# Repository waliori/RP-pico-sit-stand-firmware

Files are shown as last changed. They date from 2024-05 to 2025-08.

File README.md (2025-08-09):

# Smart Sit-Stand Desk Controller






A comprehensive and intelligent sit-stand desk controller built on Raspberry Pi Pico W, featuring WiFi connectivity, web API, and sophisticated safety mechanisms. Advanced collision detection with PCA is currently under development.

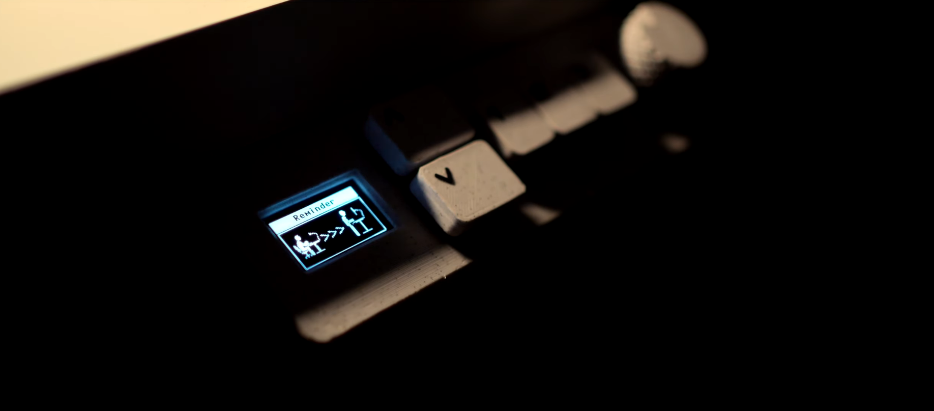
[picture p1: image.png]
The controller! Controller


🎬 **[Watch the Build Journey](https://www.youtube.com/watch?v=PKzvHBzcGJ4)** - Experience the development adventure and see the system in action

## 🌟 Features

### 🔧 Hardware Integration
- **Raspberry Pi Pico W** - Main controller with WiFi connectivity
- **H-Bridge Motor Control** - Precise linear actuator control with PWM
- **Multi-Sensor Safety System**:
  - Current sensing (ACS712 30A sensor)
  - 3-axis accelerometer (ADXL345)
  - Dual quadrature encoders (separate position tracking and UI navigation)
- **Professional UI**:
  - 128x64 OLED display (SH1106)
  - Dual rotary encoder system (UI navigation + position feedback)
  - Multiple tactile buttons
  - Audio/haptic feedback (buzzer + vibration motor)

### 🧠 Intelligent Features
- **Advanced Collision Detection** using Principal Component Analysis (PCA) ⚠️ *Work In Progress*
- **Multi-sensor Fusion** for enhanced safety and precision ⚠️ *Collision detection WIP*
- **Basic Safety Monitoring** with current sensing and position limits
- **WiFi Connectivity** with web-based configuration interface
- **RESTful API** for remote control and integration
- **Preset Height Management** (3 programmable positions)
- **Smart Sleep/Wake System** with posture reminders
- **Comprehensive Calibration System** for setup and maintenance
- **Dual Encoder System** - Separate position feedback and UI navigation

### 🔒 Safety & Reliability
- **Current Monitoring** to prevent motor overload
- **Position Limits** with software and hardware enforcement  
- **Graceful Error Handling** with user feedback
- **Persistent Configuration** storage with JSON files
- **Thread-safe Operations** with proper locking mechanisms
- **Future: Advanced Collision Detection** ⚠️ *Under Development*

## 📋 Table of Contents

1. [Project Status](#-project-status)
2. [Hardware Requirements](#-hardware-requirements)
3. [Pin Configuration](#-pin-configuration)
4. [Software Architecture](#-software-architecture)
5. [Installation & Setup](#-installation--setup)
6. [Configuration](#-configuration)
7. [API Reference](#-api-reference)
8. [Troubleshooting](#-troubleshooting)
9. [Contributing](#-contributing)
10. [License](#-license)

## 📊 Project Status

This project is part of the **[Micropython sit/stand smart table](https://github.com/users/waliori/projects/1)** development roadmap.

### ✅ Completed Features
- Core motor control with H-bridge integration
- WiFi connectivity and web interface
- OLED display with menu system
- Position tracking with encoders
- Preset height management
- RESTful API for remote control
- Configuration system with JSON storage

### 🚧 Work In Progress
- **Advanced Collision Detection** (PCA-based algorithm)
- **Multi-sensor Fusion** for enhanced safety
- **API collision detection endpoints**
- **Enhanced user guide and documentation**
- **Audio/sound system improvements**

### 📅 Planned Features
- Over-the-air (OTA) updates
- Enhanced web interface
- Mobile app integration
- Advanced logging and diagnostics
- Community-contributed features

### 🔗 Project Links
- **Main Project Board**: https://github.com/users/waliori/projects/1
- **Repository**: https://github.com/waliori/RP-pico-sit-stand-firmware
- **Issues & Features**: https://github.com/waliori/RP-pico-sit-stand-firmware/issues

## 🔌 Hardware Requirements

### Core Components

| Component | Model/Specification | Quantity | Notes |
|---|---|---|---|
| **Microcontroller** | Raspberry Pi Pico W | 1 | WiFi-enabled version required |
| **Motor Driver** | H-Bridge (capable of handling desk motor) | 1 | PWM-controlled, sufficient current rating |
| **Current Sensor** | ACS712-30A | 1 | 30A version, 66mV/A sensitivity |
| **Accelerometer** | ADXL345 | 1 | 3-axis, I2C interface |
| **Display** | SH1106 OLED 128x64 | 1 | I2C interface |
| **Position Encoder** | Quadrature Encoder (left side) | 1 | Motor position feedback only |
| **UI Encoder** | Rotary Encoder with Button (right side) | 1 | UI navigation only |
| **Buttons** | Tactile Push Buttons | 5 | Up, Down, Preset 1-3 |
| **Audio Feedback** | PWM Buzzer | 1 | Piezo buzzer, PWM-driven |
| **Haptic Feedback** | Vibration Motor | 1 | Small DC motor |

### Supporting Components

- **12V Power Supply**: For motor power
- **3.3V Regulator**: Powers all electronics from 12V  
- **Custom PCB**: For component mounting and connections
- **Connection Wires**: For linking components
- **3D Printed Parts**: Custom enclosures and mounting solutions

**Notes**: 
- All electronics run on 3.3V (except motor which uses 12V)
- Uses Pico W's internal pull-up resistors - no external resistors needed
- **🎨 3D Models**: Full CAD files available at [OnShape CAD Document](https://cad.onshape.com/documents/f9483c31494feda60f507100/w/67832ca84d886d2bfa4006b1/e/62aed646cd76d0a16e7ccfc5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)
- **📐 Wiring Diagrams**: 
  - [Wiring Diagram (PDF)](docs/schematics/wiring-diagram.pdf) - Complete breadboard-style wiring schematic
  - [Wiring Diagram (Fritzing)](docs/schematics/wiring-diagram.fzz) - Editable Fritzing source file
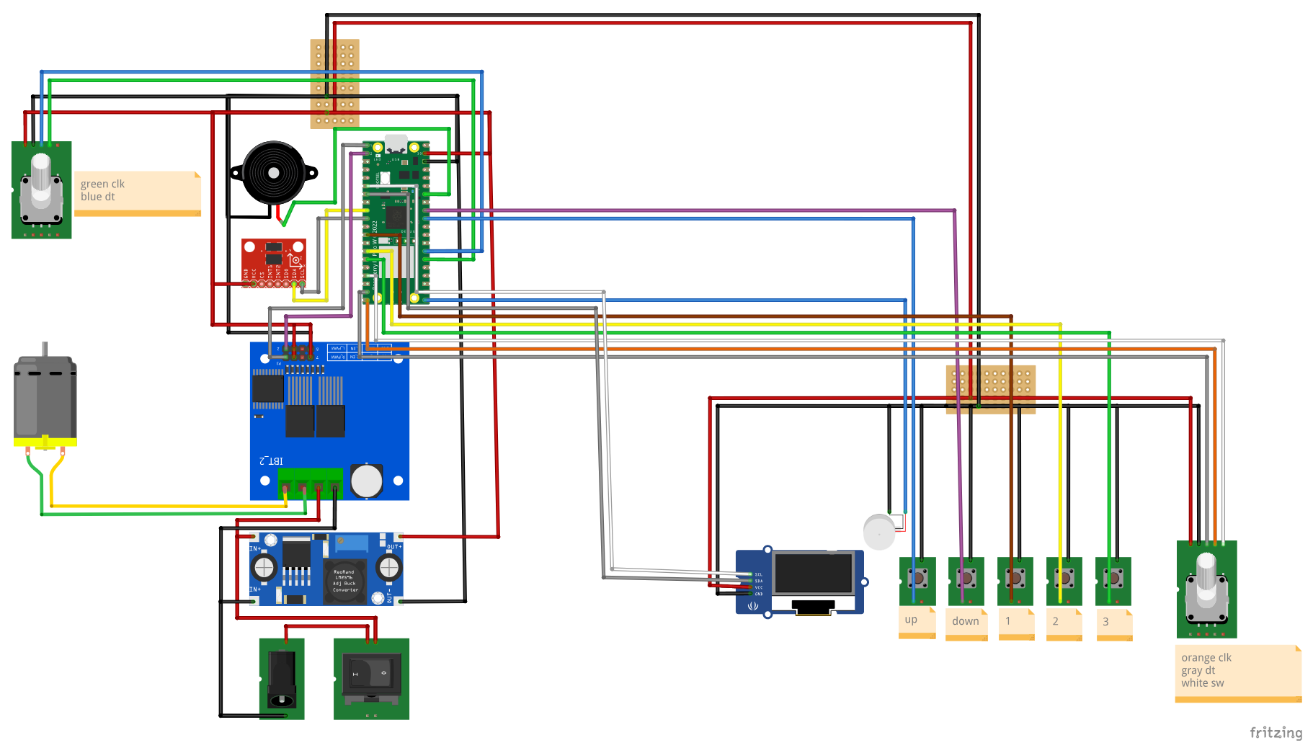
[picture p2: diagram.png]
The diagram! Wiring diagram
  

## 📍 Pin Configuration

### Raspberry Pi Pico W Pinout

```
╭─────────────────────────────────────╮
│              GPIO ASSIGNMENTS        │
├─────────────────────────────────────┤
│ Motor Control:                      │
│   GPIO 0  - H-Bridge R_PWM (Right)  │
│   GPIO 1  - H-Bridge L_PWM (Left)   │
│                                     │
│ Display & Communication (I2C0):     │
│   GPIO 4  - OLED SDA                │
│   GPIO 5  - OLED SCL                │
│                                     │
│ Sensors (I2C1):                     │
│   GPIO 6  - Accelerometer SDA       │
│   GPIO 7  - Accelerometer SCL       │
│                                     │
│ User Interface:                     │
│   GPIO 9  - Preset Button 1         │
│   GPIO 10 - Preset Button 2         │
│   GPIO 11 - Preset Button 3         │
│   GPIO 13 - UI Encoder Button       │
│   GPIO 14 - UI Encoder DT           │
│   GPIO 15 - UI Encoder CLK          │
│                                     │
│ Motor Position Encoder (Left):      │
│   GPIO 20 - Position Encoder CLK    │
│   GPIO 21 - Position Encoder DT     │
│                                     │
│ Audio/Haptic Feedback:              │
│   GPIO 16 - Vibration Motor         │
│   GPIO 22 - PWM Buzzer              │
│                                     │
│ Control Buttons:                    │
│   GPIO 26 - Down Button             │
│   GPIO 27 - Up Button               │
│                                     │
│ Analog Input:                       │
│   GPIO 28 - Current Sensor (ADC)    │
╰─────────────────────────────────────╯
```

### Connection Diagrams

#### Power Connections
```
Pico W 3.3V ──┬── All Electronics:
                ├── OLED Display
                ├── Accelerometer
                ├── Current Sensor
                ├── Rotary Encoders
                └── Buttons & Buzzer

12V Supply ─────── Motor (via H-Bridge)

Common GND ─────── All components
```

#### I2C Bus Configuration
```
I2C0 (Display):          I2C1 (Sensors):
GPIO 4 (SDA) ──── OLED   GPIO 6 (SDA) ──── ADXL345
GPIO 5 (SCL) ──── OLED   GPIO 7 (SCL) ──── ADXL345
```

#### Dual Encoder Configuration
```
Left Encoder (Position):     Right Encoder (UI):
GPIO 20 (CLK) ──── Motor     GPIO 15 (CLK) ──── Menu Navigation
GPIO 21 (DT)  ──── Position  GPIO 14 (DT)  ──── Menu Navigation
                             GPIO 13 (SW)  ──── Menu Button
```

## 🏗️ Software Architecture

### System Overview

```
┌─────────────────────────────────────────────────────────────┐
│                     Application Layer                       │
├─────────────────────────────────────────────────────────────┤
│  main.py           │  Setup & Main Loop                     │
│  menu.py           │  User Interface Management             │
│  wifi.py           │  Network & Web Interface              │
├─────────────────────────────────────────────────────────────┤
│                    Control Layer                            │
├─────────────────────────────────────────────────────────────┤
│  motor.py          │  Motor Control & Basic Safety         │
│  calibration.py    │  System Calibration & Configuration   │
│  presets.py        │  Height Preset Management             │
│  collision.py      │  🚧 Collision Detection (WIP)         │
├─────────────────────────────────────────────────────────────┤
│                   Hardware Layer                            │
├─────────────────────────────────────────────────────────────┤
│  display.py        │  OLED Display Management               │
│  accelerometer.py  │  Motion Sensor Interface              │
│  acs712.py         │  Current Sensor Interface             │
│  buzz_vib.py       │  Audio/Haptic Feedback                │
├─────────────────────────────────────────────────────────────┤
│                   Support Layer                             │
├─────────────────────────────────────────────────────────────┤
│  songs.py          │  Audio Notification Patterns          │
│  rtttl.py          │  Music Format Parser                  │
│  sh1106.py         │  OLED Display Driver                  │
│  writer.py         │  Font Rendering System                │
└─────────────────────────────────────────────────────────────┘
```

### Core Modules

#### 1. Motor Control System (`motor.py`)
- **PWM Motor Control**: Precision speed and direction control
- **Encoder Integration**: Real-time position feedback
- **Basic Safety Monitoring**: Current monitoring and position limits
- **API Support**: Asynchronous motor control for web interface
- **Future: PCA-based Analysis** ⚠️ *Under Development*

#### 2. Collision Detection (`collision.py`) 🚧 *Work In Progress*
- **⚠️ Development Status**: Advanced collision detection is currently being implemented
- **Planned Features**: Principal Component Analysis for statistical anomaly detection
- **Future Capabilities**: Multi-sensor fusion (accelerometer + current + RPM)
- **Target Features**: Adaptive thresholds and direction-specific detection
- **Current Status**: Basic framework in place, algorithm implementation ongoing

#### 3. Calibration System (`calibration.py`)
- **Multi-phase Setup**: Height limits, sensor baselines, safety thresholds
- **Persistent Storage**: JSON-based configuration management
- **Real-time Updates**: Dynamic recalibration capabilities
- **Height Mapping**: Encoder-to-real-world height conversion
- **Safety Validation**: Limit verification and enforcement

#### 4. WiFi & Web Interface (`wifi.py`)
- **Auto-connection**: Intelligent network discovery and connection
- **Access Point Mode**: Fallback configuration interface
- **Web Portal**: HTML-based setup and control interface
- **RESTful API**: Complete remote control capabilities
- **Security**: Password-protected networks and saved credentials

#### 5. Display System (`display.py`)
- **Multi-font Support**: 20pt and 30pt font rendering
- **Icon System**: WiFi, lock, sound, and status indicators
- **Menu Framework**: Hierarchical navigation system
- **Animation Support**: Progress bars and visual feedback
- **Power Management**: Sleep and wake functionality

### Data Flow Architecture

```
┌─────────────────────────────────────────────────────────────┐
│                    DUAL ENCODER SYSTEM                     │
├─────────────────────────────────────────────────────────────┤
│  Position Encoder (Left) ──► Motor Control ──► Basic Safety │
│     GPIO 20/21                     │              │         │
│                                    ▼              ▼         │
│  UI Encoder (Right) ──► Display ──► Height Display Safety   │
│     GPIO 13/14/15       System       Updates     Actions   │
│                           │                                 │
│  Physical Buttons ────────┤                                 │
│  (Up/Down/Presets)        │                                 │
│                           ▼                                 │
│                      Menu Navigation                        │
└─────────────────────────────────────────────────────────────┘
                           │
                           ▼
┌─────────────────────────────────────────────────────────────┐
│                    SENSOR FUSION                           │
├─────────────────────────────────────────────────────────────┤
│  Accelerometer (GPIO 6/7) ──┐                              │
│                              ├─► Safety Monitoring         │
│  Current Sensor (GPIO 28) ───┘         │                   │
│                                         ▼                   │
│                              🚧 Future: Advanced Collision  │
│                                 Detection (PCA-based)       │
└─────────────────────────────────────────────────────────────┘
                           │
                           ▼
┌─────────────────────────────────────────────────────────────┐
│                  CONTROL INTERFACES                        │
├─────────────────────────────────────────────────────────────┤
│  Web API (WiFi) ──────────┐                                │
│                           ├─► Motor Commands               │
│  Physical Controls ───────┘     │                          │
│  (Buttons/Encoders)              ▼                          │
│                            H-Bridge Control                │
│                            (GPIO 0/1 PWM)                  │
└─────────────────────────────────────────────────────────────┘
                           │
                           ▼
┌─────────────────────────────────────────────────────────────┐
│                 PERSISTENT STORAGE                         │
├─────────────────────────────────────────────────────────────┤
│  settings.json ◄─── Calibration System                     │
│  presets.json  ◄─── Preset Management                      │
│  state.json    ◄─── Current Position                       │
│  saved_wifi.json ◄─ Network Credentials                    │
└─────────────────────────────────────────────────────────────┘
```

## 🚀 Installation & Setup

### Prerequisites

1. **MicroPython Firmware**: Install latest MicroPython on Raspberry Pi Pico W
2. **Development Environment**: 
   - Thonny IDE (recommended for beginners)
   - VS Code with MicroPython extension
   - Command line tools (ampy, rshell, mpremote)

### Step 1: Hardware Assembly

1. **Connect Components** according to the pin configuration above
2. **Verify Power Supply** ratings and connections
3. **Test Individual Components** before full assembly
4. **Secure Connections** and check for shorts

### Step 2: Firmware Installation

```bash
# Clone the repository
git clone https://github.com/waliori/RP-pico-sit-stand-firmware.git
cd RP-pico-sit-stand-firmware

# Upload files to Pico W (using mpremote)
mpremote fs cp *.py :
mpremote fs cp lib/* :lib/

# Alternative: Using Thonny IDE
# 1. Open Thonny
# 2. Configure for Raspberry Pi Pico
# 3. Upload all .py files to the device
```

### Step 3: Initial Configuration

1. **Power On**: The system will start in calibration mode
2. **Height Calibration**:
   - Move desk to highest position → Press and hold rotary encoder
   - Set maximum height value using rotary encoder
   - Move desk to lowest position → Press and hold rotary encoder  
   - Set minimum height value using rotary encoder
3. **WiFi Setup**: 
   - Connect to "PicoW" access point (password: waliori123)
   - Navigate to 192.168.4.1
   - Configure WiFi credentials

### Step 4: Safety Calibration

1. **Collision Calibration**:
   - Access "Collision Reset" from main menu
   - Move desk through full range while system learns normal operation
   - Confirm calibration completion

2. **Verification**:
   - Test all movement directions
   - Verify collision detection with safe obstacles
   - Confirm preset functionality

## ⚙️ Configuration

### System Settings (`settings.json`)

```json
{
  "min_encoder": 0,
  "max_encoder": 5000,
  "min_real": 72.0,
  "max_real": 120.0,
  "sleep_time": 30,
  "reminder_time": 5400,
  "rpm_up": 120.0,
  "rpm_down": 115.0,
  "current_up": 2.5,
  "current_down": 2.2,
  "accel_up": [100, 150, 980],
  "accel_down": [95, 145, 985],
  "principal_components_up": [[...], [...]],
  "principal_components_down": [[...], [...]],
  "projected_mean_up": [0.5, 0.3],
  "projected_mean_down": [0.4, 0.2]
}
```

### WiFi Configuration (`saved_wifi.json`)

```json
{
  "HomeNetwork": "password123",
  "OfficeWiFi": "securepass456"
}
```

### Preset Heights (`presets.json`)

```json
{
  "1": 2500,
  "2": 3750,
  "3": 4200
}
```

### Menu System Navigation

```
Main Menu
├── WiFi
│   ├── Connect to saved networks
│   ├── Scan for new networks
│   ├── Access Point mode
│   └── API toggle
├── Configuration
│   ├── Sleep timer settings
│   ├── Min/Max height adjustment
│   ├── Posture reminder timer
│   ├── Vibration on/off
│   └── Sound settings
├── Lock/Unlock
├── Show Presets
├── Show Min/Max
├── Collision Reset
└── Factory Reset
```

## 🌐 API Reference

### Base URL
```
http://<pico-ip-address>/
```

### Endpoints

#### Status & Information

**Get Current Height**
```http
GET /get_height
```
Response:
```json
{"height": "95.5"}
```

**Get Min/Max Heights**
```http
GET /get_minmax
```
Response:
```json
{"min": 72.0, "max": 120.0}
```

**Get Presets**
```http
GET /get_presets
```
Response:
```json
["1: 95.5", "2: 110.0", "3: 115.2"]
```

**Check Lock Status**
```http
GET /islocked
```
Response:
```json
{"locked": false}
```

#### Control Commands

**Move Up**
```http
GET /forward
```

**Move Down**
```http
GET /backward
```

**Stop Movement**
```http
GET /stop
```

**Go to Specific Height**
```http
GET /go?height=100.5
```

**Go to Preset**
```http
GET /go_preset?preset=1
```

#### Security & Settings

**Lock Desk**
```http
GET /lock
```

**Unlock Desk**
```http
GET /unlock
```

**Set Minimum Height**
```http
GET /set_min?min=70.0
```

**Set Maximum Height**
```http
GET /set_max?max=125.0
```

### Response Format

All API responses include CORS headers and follow this structure:

**Success Response:**
```json
{
  "status": "ok",
  "data": "..."
}
```

**Error Response:**
```json
{
  "status": "nok",
  "error": "Description of error"
}
```

## 🔧 Advanced Features

### Current Safety Features

- **Position Limits**: Software-enforced minimum and maximum heights
- **Current Monitoring**: Motor current sensing for overload protection
- **Manual Controls**: Physical buttons for direct desk control
- **Emergency Stop**: Immediate motor shutdown capability

### 🚧 Future: Advanced Collision Detection (Work In Progress)

The system is being developed to include Principal Component Analysis (PCA) for sophisticated obstacle detection:

**Planned Implementation**:
1. **Multi-sensor Data Collection**: 3-axis accelerometer, motor current, RPM
2. **Statistical Analysis**: Real-time normalization and PCA projection
3. **Adaptive Thresholds**: Dynamic sensitivity adjustment
4. **Direction-specific Calibration**: Separate learning for up/down movement

**Development Status**: Framework implemented, algorithm integration in progress

### Power Management

- **Sleep Mode**: OLED turns off after configurable timeout
- **Wake on Input**: Any button press or encoder movement
- **Posture Reminders**: Configurable alerts for movement
- **Low Power WiFi**: Optimized power management for wireless

### Security Features

- **Physical Lock**: Disable all movement commands
- **API Authentication**: Future expansion capability
- **Safe Mode**: Reduced sensitivity for maintenance
- **Position Limits**: Software-enforced boundaries

## 🐛 Troubleshooting

### Common Issues

**Problem**: Desk doesn't move when buttons are pressed
- **Check**: Motor driver connections and power supply
- **Check**: H-bridge enable signals and PWM outputs  
- **Check**: Encoder connections for position feedback
- **Solution**: Verify all connections match pin configuration

**Problem**: Basic safety monitoring issues
- **Check**: Current sensor calibration and connections
- **Check**: Position encoder feedback
- **Solution**: Verify sensor connections and recalibrate system
- **Note**: Advanced collision detection is under development

**Problem**: WiFi connection fails
- **Check**: Network credentials in saved_wifi.json
- **Check**: WiFi signal strength and network availability
- **Solution**: Use access point mode for reconfiguration

**Problem**: Display shows incorrect height
- **Check**: Encoder connections and mechanical coupling
- **Solution**: Run full height calibration sequence

**Problem**: System freezes or becomes unresponsive
- **Check**: Power supply stability and current capacity
- **Check**: I2C bus conflicts or wiring issues
- **Solution**: Power cycle and check console output

### Debug Mode

Enable debug output by modifying `main.py`:

```python
DEBUG = True  # Add this line at the top

# Add debug prints throughout code
if DEBUG:
    print(f"Debug: Current height = {height}")
```

### Log Analysis

Monitor system behavior through UART:

```bash
# Using screen (Linux/Mac)
screen /dev/ttyACM0 115200

# Using PuTTY (Windows)
# Connect to COM port at 115200 baud
```

### Factory Reset

1. **Software Reset**: Access "Factory Reset" from main menu
2. **Hardware Reset**: Hold BOOTSEL button while powering on
3. **Full Reinstall**: Re-upload all firmware files

## 🤝 Contributing

We welcome contributions to improve this project!

### Development Setup

1. **Fork the Repository**
2. **Create Feature Branch**: `git checkout -b feature/amazing-feature`
3. **Install Development Tools**:
   ```bash
   pip install micropython-stubs
   pip install black  # Code formatting
   pip install pylint # Code analysis
   ```

### Code Standards

- **Python Style**: Follow PEP 8 guidelines
- **Documentation**: Include docstrings for all functions
- **Comments**: Explain complex logic and hardware interactions
- **Testing**: Test on actual hardware before submitting

### Contribution Areas

- **Hardware Support**: Additional sensor integrations
- **Safety Features**: Enhanced collision detection algorithms
- **UI Improvements**: Better display layouts and animations
- **API Extensions**: Additional control endpoints
- **Documentation**: Tutorials, guides, and examples

### Pull Request Process

1. **Update Documentation** for any new features
2. **Test Thoroughly** on hardware
3. **Update Version Numbers** if applicable
4. **Submit Pull Request** with clear description

## 📜 License

This project is licensed under the MIT License - see the [LICENSE](LICENSE) file for details.

```
MIT License

Copyright (c) 2024 waliori

Permission is hereby granted, free of charge, to any person obtaining a copy
of this software and associated documentation files (the "Software"), to deal
in the Software without restriction, including without limitation the rights
to use, copy, modify, merge, publish, distribute, sublicense, and/or sell
copies of the Software, and to permit persons to whom the Software is
furnished to do so, subject to the following conditions:

The above copyright notice and this permission notice shall be included in all
copies or substantial portions of the Software.

THE SOFTWARE IS PROVIDED "AS IS", WITHOUT WARRANTY OF ANY KIND, EXPRESS OR
IMPLIED, INCLUDING BUT NOT LIMITED TO THE WARRANTIES OF MERCHANTABILITY,
FITNESS FOR A PARTICULAR PURPOSE AND NONINFRINGEMENT. IN NO EVENT SHALL THE
AUTHORS OR COPYRIGHT HOLDERS BE LIABLE FOR ANY CLAIM, DAMAGES OR OTHER
LIABILITY, WHETHER IN AN ACTION OF CONTRACT, TORT OR OTHERWISE, ARISING FROM,
OUT OF OR IN CONNECTION WITH THE SOFTWARE OR THE USE OR OTHER DEALINGS IN THE
SOFTWARE.
```

## 🙏 Acknowledgments

- **Raspberry Pi Foundation** for the excellent Pico W platform
- **MicroPython Community** for the robust embedded Python implementation
- **Open Source Libraries**: SH1106, ADXL345, and other hardware drivers
- **Contributors**: All developers who have helped improve this project

## 📞 Support

- **Issues**: [GitHub Issues](https://github.com/waliori/RP-pico-sit-stand-firmware/issues)
- **Discussions**: [GitHub Discussions](https://github.com/waliori/RP-pico-sit-stand-firmware/discussions)
- **Build Video**: [🎬 YouTube Documentary](https://www.youtube.com/watch?v=PKzvHBzcGJ4) - Complete build process
- **Email**: Contact the maintainer through GitHub profile

---

**⚠️ Safety Notice**: This controller manages potentially dangerous mechanical equipment. Always verify all safety features are working correctly before use. Never bypass safety mechanisms. Use appropriate electrical protection and follow local electrical codes.

**🔌 Electrical Warning**: This project involves mains-powered equipment. Ensure proper electrical isolation and safety measures. When in doubt, consult a qualified electrician.

---

Made with ❤️ by [waliori](https://walior.it) | [Project Website](https://github.com/waliori/RP-pico-sit-stand-firmware)

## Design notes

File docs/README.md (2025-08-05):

# Smart Sit-Stand Desk Controller - Documentation

Documentation for the Smart Sit-Stand Desk Controller project built with Raspberry Pi Pico W and MicroPython.

🎬 **[Watch the Build Journey](https://www.youtube.com/watch?v=PKzvHBzcGJ4)** - Experience the development adventure and see the finished system in action.

⚠️ **Project Status**: Advanced collision detection features are currently Work In Progress as part of the [Micropython sit/stand smart table project](https://github.com/users/waliori/projects/1).

## 📋 Documentation

### Hardware
- **[Hardware Overview](hardware/overview.md)** - Components and pin assignments
- **[Bill of Materials](hardware/bom.md)** - Electronic components list
- **[3D Models & CAD Files](https://cad.onshape.com/documents/f9483c31494feda60f507100/w/67832ca84d886d2bfa4006b1/e/62aed646cd76d0a16e7ccfc5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)** - Open-source CAD models

### Software  
- **[System Architecture](software/architecture.md)** - Software design and modules

### API
- **[REST API Reference](api/rest-api.md)** - HTTP API documentation

### Setup
- **[Quick Start Guide](setup/quick-start.md)** - Setup instructions

## 🎯 Quick Navigation

### For New Users
1. Check [Hardware Overview](hardware/overview.md) for components
2. Follow [Quick Start Guide](setup/quick-start.md) for setup
3. Use [REST API Reference](api/rest-api.md) for control

### For Developers
1. Review [System Architecture](software/architecture.md)
2. Study [REST API Reference](api/rest-api.md)

## 📋 Project Overview

This documentation covers a sit-stand desk controller featuring:

- **Basic Safety**: Position limits, current monitoring
- **WiFi Control**: Web interface and REST API  
- **OLED Display**: Menu navigation with rotary encoder
- **Position Tracking**: Encoder feedback
- **Future: Advanced Collision Detection** ⚠️ PCA-based (under development)

### 🎬 Build Story

Experience the complete development journey in the [YouTube documentary](https://www.youtube.com/watch?v=PKzvHBzcGJ4).

## 📈 Project Status

### ✅ Completed Features
- Motor control and position tracking
- WiFi connectivity and web interface
- Basic safety monitoring (current sensing, position limits)
- OLED display with menu navigation
- RESTful API for remote control

### 🚧 Work In Progress
- **Advanced Collision Detection**: PCA-based algorithm implementation

### 🔗 Project Links
- **🎬 Build Documentary**: https://www.youtube.com/watch?v=PKzvHBzcGJ4
- **Main Project Board**: https://github.com/users/waliori/projects/1
- **Repository**: https://github.com/waliori/RP-pico-sit-stand-firmware

---

**📞 Support**: [GitHub Issues](https://github.com/waliori/RP-pico-sit-stand-firmware/issues)

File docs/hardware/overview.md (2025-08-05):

# Hardware Overview

Hardware components and connections for the Smart Sit-Stand Desk Controller.

## 🔌 Core Components

### Primary Controller
- **Raspberry Pi Pico W** - Main microcontroller with WiFi

### Motor Control System
- **BTS7960B H-Bridge** - Motor driver module
- **37GB555 Geared Motor** - 12V 180RPM DC motor with encoder

### Sensor System
- **ACS712-30A** - Current sensor module
- **ADXL345** - 3-axis accelerometer

### User Interface
- **SH1106 OLED** - 128x64 monochrome display
- **KY-040 Rotary Encoder** - 360° rotary encoder with button (1x UI navigation)
- **KY-040 Rotary Encoder** - 360° rotary encoder (1x motor position feedback)
- **Tactile Buttons** - Push buttons for controls (5x)

### Additional Components
- **12V Power Adapter** - AC to DC power supply
- **LM2596 Buck Converter** - DC-DC step down module
- **Buzzer** - Piezo buzzer (PWM driven)
- **Vibration Motor** - Coin vibration motor 3V
- **Connection Wires** - For linking components
- **3D Printed Enclosures** - Custom housings and mounts (CAD files available)

## 🔗 Pin Assignments

| GPIO | Function | Component | Notes |
|---|---|---|---|
| 0 | PWM | H-Bridge R_PWM | Motor forward |
| 1 | PWM | H-Bridge L_PWM | Motor reverse |
| 4 | I2C SDA | OLED Display | I2C0 Bus |
| 5 | I2C SCL | OLED Display | I2C0 Bus |
| 6 | I2C SDA | Accelerometer | I2C1 Bus |
| 7 | I2C SCL | Accelerometer | I2C1 Bus |
| 9 | Digital | Preset Button 1 | Internal pull-up |
| 10 | Digital | Preset Button 2 | Internal pull-up |
| 11 | Digital | Preset Button 3 | Internal pull-up |
| 13 | Digital | UI Encoder SW | Button switch (right encoder) |
| 14 | Digital | UI Encoder DT | Data signal (right encoder) |
| 15 | Digital | UI Encoder CLK | Clock signal (right encoder) |
| 16 | Digital | Vibration Motor | Output |
| 20 | Digital | Position Enc CLK | Motor encoder (left encoder) |
| 21 | Digital | Position Enc DT | Motor encoder (left encoder) |
| 22 | PWM | Buzzer | Audio feedback |
| 26 | Digital | Down Button | Motor control |
| 27 | Digital | Up Button | Motor control |
| 28 | ADC | Current Sensor | Analog input |

## ⚡ Power Configuration

```
Power Rails:
├── 12V (Motor Power)
│   └── Linear Actuator (via H-Bridge)
│
├── 3.3V (All Electronics)
│   ├── Raspberry Pi Pico W
│   ├── H-Bridge Control Logic
│   ├── OLED Display (SH1106)
│   ├── Accelerometer (ADXL345)
│   ├── Current Sensor (ACS712)
│   ├── Rotary Encoders
│   ├── Tactile Buttons
│   ├── Buzzer
│   └── Vibration Motor
│
└── GND (Common Ground)
    └── All components share common ground
```

## 🔌 Connection Summary

### I2C Bus Configuration
```
I2C0 (Display):          I2C1 (Sensors):
GPIO 4 (SDA) ──── OLED   GPIO 6 (SDA) ──── ADXL345
GPIO 5 (SCL) ──── OLED   GPIO 7 (SCL) ──── ADXL345
```

### Motor Control
```
GPIO 0 → H-Bridge R_PWM (Forward)
GPIO 1 → H-Bridge L_PWM (Reverse)
GPIO 20 → Position Encoder CLK
GPIO 21 → Position Encoder DT
GPIO 28 → Current Sensor Output
```

### User Interface
```
GPIO 13 → UI Encoder Button (right encoder)
GPIO 14 → UI Encoder DT (right encoder)
GPIO 15 → UI Encoder CLK (right encoder)
GPIO 26 → Down Button
GPIO 27 → Up Button
GPIO 9/10/11 → Preset Buttons 1/2/3
```

**Note**: All buttons use the Pico W's internal pull-up resistors - no external resistors needed.

**Encoder Configuration**:
- **Left Encoder**: Position feedback only (GPIO 20/21)
- **Right Encoder**: UI navigation with button (GPIO 13/14/15)

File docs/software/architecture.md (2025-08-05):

# Software Architecture

This document provides a comprehensive overview of the software architecture for the Smart Sit-Stand Desk Controller, including system design patterns, module organization, and data flow.

## 🏗️ Architectural Overview

The software follows a **layered architecture** pattern with clear separation of concerns, implementing **object-oriented design** principles for maintainability and extensibility.

```
┌─────────────────────────────────────────────────────────────┐
│                     APPLICATION LAYER                       │
├─────────────────────────────────────────────────────────────┤
│  main.py           │  Application bootstrap and main loop   │
│  menu.py           │  User interface state management       │
│  wifi.py           │  Network services and web interface    │
├─────────────────────────────────────────────────────────────┤
│                     BUSINESS LOGIC LAYER                    │
├─────────────────────────────────────────────────────────────┤
│  motor.py          │  Motor control and basic safety        │
│  calibration.py    │  System configuration and calibration  │
│  presets.py        │  Height preset management              │
│  collision.py      │  🚧 Collision detection (WIP)          │
├─────────────────────────────────────────────────────────────┤
│                     HARDWARE ABSTRACTION LAYER              │
├─────────────────────────────────────────────────────────────┤
│  display.py        │  OLED display management               │
│  accelerometer.py  │  Motion sensor interface               │
│  acs712.py         │  Current sensor interface              │
│  buzz_vib.py       │  Audio/haptic feedback                 │
├─────────────────────────────────────────────────────────────┤
│                     DRIVER LAYER                            │
├─────────────────────────────────────────────────────────────┤
│  sh1106.py         │  OLED display driver                   │
│  writer.py         │  Font rendering system                 │
│  songs.py          │  Audio pattern definitions             │
│  rtttl.py          │  Music format parser                   │
└─────────────────────────────────────────────────────────────┘
```

## 🎯 Design Principles

### 1. Separation of Concerns
- **Hardware abstraction** isolates low-level sensor/actuator interfaces
- **Business logic** implements core functionality independent of hardware
- **User interface** handles presentation and user interaction
- **Network services** manage connectivity and remote access

### 2. Thread Safety
- **Shared resources** protected with locks (`_thread.allocate_lock()`)
- **Critical sections** properly synchronized for display and file I/O
- **Atomic operations** for sensor readings and motor control

### 3. Fault Tolerance
- **Graceful degradation** when components fail
- **Error recovery** mechanisms for network and hardware issues
- **Safe defaults** for all configuration parameters
- **Watchdog timers** for critical operations

### 4. Modularity
- **Loose coupling** between modules through well-defined interfaces
- **High cohesion** within individual modules
- **Dependency injection** for testability and flexibility
- **Plugin architecture** for future extensions

## 📊 Data Flow Architecture

```
┌─────────────┐    ┌─────────────┐    ┌─────────────┐
│   Sensors   │───►│   Motor     │───►│ Collision   │
│             │    │  Control    │    │ Detection   │
│ • ADXL345   │    │             │    │             │
│ • ACS712    │    │ • Position  │    │ • PCA       │
│ • Encoder   │    │ • Speed     │    │ • Threshold │
└─────────────┘    │ • Current   │    │ • Safety    │
                   └─────────────┘    └─────────────┘
                          │                   │
                          ▼                   ▼
                   ┌─────────────┐    ┌─────────────┐
                   │   Display   │    │   Safety    │
                   │   System    │    │  Actions    │
                   │             │    │             │
                   │ • Status    │    │ • Stop      │
                   │ • Height    │    │ • Alert     │
                   │ • Menu      │    │ • Log       │
                   └─────────────┘    └─────────────┘
                          ▲
                          │
                   ┌─────────────┐    ┌─────────────┐
                   │ User Input  │    │    WiFi     │
                   │             │    │   API       │
                   │ • Buttons   │───►│             │
                   │ • Encoder   │    │ • REST      │
                   │ • Menu      │    │ • WebSocket │
                   └─────────────┘    └─────────────┘
```

## 🔧 Module Architecture

### Core Control Module (`motor.py`)

**Class: Motor**
```python
class Motor:
    def __init__(self, pwm1, pwm2, counter, sLock, accelO, curr_sens):
        # Hardware interfaces
        self.pwm1 = pwm1              # Forward PWM (GPIO 0)
        self.pwm2 = pwm2              # Reverse PWM (GPIO 1)
        self.counter = counter        # Position encoder (left encoder, GPIO 20/21)
        self.sLock = sLock           # Thread lock
        self.accelO = accelO         # Accelerometer object (GPIO 6/7)
        self.curr_sens = curr_sens   # Current sensor object (GPIO 28)
        
        # State variables
        self.direction = 0           # 0=stop, 1=up, -1=down
        self.rpm = 0                 # Current RPM
        self.blocked = False         # Collision state
        
        # PCA variables for collision detection
        self.principal_components_up = None
        self.principal_components_down = None
        self.projected_mean_up = None
        self.projected_mean_down = None
```

**Key Methods:**
- `move_motor()` - Manual button control with safety
- `move_motor_height()` - Automated movement to specific position
- `move_motor_api()` - Asynchronous API-controlled movement
- `encoder()` - Position tracking and RPM calculation
- `rpm_updt()` - Sensor data collection and processing
- **Future**: `update_pca()` - Real-time PCA learning and analysis ⚠️ *Under Development*

### Collision Detection Module (`collision.py`) 🚧 *Work In Progress*

**⚠️ Development Status**: This module is currently under active development as part of the [Micropython sit/stand smart table project](https://github.com/users/waliori/projects/1).

**Current Implementation**:
```python
class Collision:
    def __init__(self, calibrationO):
        # Basic framework in place
        self.calibration_data = calibrationO.calib
        # Advanced algorithm implementation in progress
```

**Planned Algorithm Overview (Under Development)**:
1. **Data Collection**: Multi-sensor readings (accelerometer, current, RPM)
2. **Normalization**: Scale all sensor values to 0-1 range  
3. **PCA Projection**: Project onto learned principal components
4. **Distance Calculation**: Mahalanobis distance from normal operation
5. **Adaptive Thresholding**: Dynamic threshold based on historical data
6. **Decision Making**: Collision detected if distance exceeds threshold

**Implementation Status**: Basic class structure exists, advanced PCA algorithm in development.

### Display Management (`display.py`)

**Class: Display**
```python
class Display:
    def __init__(self, width, height, i2c_id, scl, sda, buzzvibO, freq=400000):
        self.oled = SH1106_I2C(width, height, i2c, rotate=180)  # I2C0, GPIO 4/5
        self.font_writer_20 = writer.Writer(self.oled, freesans20)
        self.font_writer_30 = writer.Writer(self.oled, firacodeBold30)
        
        # UI encoder interface (right encoder, GPIO 13/14/15)
        self.ui_encoder_clk = Pin(15, Pin.IN, Pin.PULL_UP)
        self.ui_encoder_dt = Pin(14, Pin.IN, Pin.PULL_UP)
        self.ui_encoder_sw = Pin(13, Pin.IN, Pin.PULL_UP)
        
        # Menu state
        self.menu_line = 1
        self.menu_highlight = 1
        self.menu_shift = 0
        
        # Power management
        self.sleep_state = False
        self.reminder_time = 0
```

**Key Features:**
- **Multi-font rendering** with custom font files
- **Icon system** for status indicators (WiFi, lock, sound)
- **Menu framework** with scrolling and highlighting (right encoder navigation)
- **Power management** with sleep/wake functionality
- **Animation support** for progress bars and transitions
- **Dual encoder support**: Position feedback (left) and UI navigation (right)

### Network Services (`wifi.py`)

**Class: Wifi**
```python
class Wifi:
    def __init__(self, app, sLock, displayO, menuO):
        self.wlan = network.WLAN(network.STA_IF)  # Station mode
        self.ap = network.WLAN(network.AP_IF)     # Access Point mode
        self.app = app                            # Microdot web framework
        self.saved_json = {}                      # Saved networks
```

**Network Modes:**
1. **Station Mode**: Connect to existing WiFi networks
2. **Access Point Mode**: Create configuration hotspot
3. **Dual Mode**: Station + AP for setup and operation

**Web Interface Features:**
- **Configuration Portal**: WiFi setup and network management
- **REST API**: Complete motor control and status endpoints
- **Real-time Updates**: WebSocket for live status monitoring
- **Security**: Saved network credentials and access control

## 🔄 Concurrency Model

### Thread Architecture

```
Main Thread (Core 0):
├── Hardware Initialization
├── Sensor Reading Loop
├── Motor Control Logic
├── Collision Detection
└── Display Updates

Network Thread (Core 1):
├── WiFi Management
├── Web Server (Microdot)
├── API Request Handling
└── WebSocket Communications

Shared Resources:
├── Display (sLock protected)
├── Motor State (atomic operations)
├── Configuration Files (sLock protected)
└── Sensor Data (lock-free queues)
```

### Synchronization Mechanisms

**Thread Locks (`_thread.allocate_lock()`)**:
```python
sLock = _thread.allocate_lock()

# Protected operations
sLock.acquire()
try:
    # Critical section
    display.update()
    file.write(data)
finally:
    sLock.release()
```

**Async/Await Pattern**:
```python
async def move_motor_api(self, direction, outA, outB, mini, maxi):
    while self.api:
        # Non-blocking motor control
        await asyncio.sleep_ms(1)
```

## 💾 Data Management

### Configuration Storage

**JSON-based Configuration**:
```python
# settings.json - System configuration
{
    "min_encoder": 0,
    "max_encoder": 5000,
    "min_real": 72.0,
    "max_real": 120.0,
    "sleep_time": 30,
    "reminder_time": 5400,
    "principal_components_up": [[...], [...]],
    "principal_components_down": [[...], [...]]
}

# presets.json - Height presets
{
    "1": 2500,
    "2": 3750, 
    "3": 4200
}

# saved_wifi.json - Network credentials
{
    "HomeNetwork": "password123",
    "OfficeWiFi": "securepass456"
}

# state.json - Current position
{
    "current_encoder": 2800
}
```

### File I/O Patterns

**Thread-safe File Operations**:
```python
def save_settings(self, data):
    self.sLock.acquire()
    try:
        with open("settings.json", "w") as file:
            file.write(json.dumps(data))
    finally:
        self.sLock.release()
```

**Error Handling**:
```python
try:
    with open("settings.json", "r") as file:
        settings = json.load(file)
except (OSError, ValueError):
    # Create default configuration
    settings = self.create_default_settings()
    self.save_settings(settings)
```

## 🔐 Security Architecture

### Access Control

**Physical Security**:
- Lock/unlock state prevents movement
- Emergency stop capability
- Position limits enforced

**Network Security**:
- WPA3 WiFi encryption
- CORS headers for web API
- Input validation and sanitization
- Rate limiting (future enhancement)

### Error Handling Strategy

**Graceful Degradation**:
```python
def safe_operation(self, operation):
    try:
        return operation()
    except HardwareError as e:
        self.log_error(e)
        self.enter_safe_mode()
        return default_value
    except NetworkError as e:
        self.log_error(e)
        self.continue_offline()
        return cached_value
```

**Recovery Mechanisms**:
- Hardware watchdog timers
- Software watchdog for critical loops
- Automatic retry for transient failures
- Factory reset capability

## 📊 Performance Characteristics

### Real-time Requirements

| Operation | Max Latency | Frequency | Priority |
|---|---|---|---|
| Collision Detection | 10ms | 100Hz | Critical |
| Position Feedback | 20ms | 50Hz | High |
| Display Update | 50ms | 20Hz | Medium |
| Network Response | 200ms | Variable | Low |

### Memory Usage

**Static Memory**:
- Code: ~150KB
- Fonts: ~20KB  
- Constants: ~5KB

**Dynamic Memory**:
- Sensor buffers: ~2KB
- Network buffers: ~8KB
- Display buffers: ~1KB
- Stack space: ~4KB per thread

### Resource Optimization

**CPU Usage**:
- Core 0: 60% (control loops)
- Core 1: 40% (network services)

**Power Optimization**:
- Sleep mode for display
- WiFi power management
- Sensor duty cycling

## 🧪 Testing Architecture

### Unit Testing Framework

**Hardware Mocking**:
```python
class MockSensor:
    def __init__(self, test_data):
        self.test_data = test_data
        self.index = 0
    
    def read(self):
        data = self.test_data[self.index]
        self.index = (self.index + 1) % len(self.test_data)
        return data
```

**Test Categories**:
1. **Unit Tests**: Individual module functionality
2. **Integration Tests**: Module interactions
3. **Hardware Tests**: Real hardware verification
4. **Stress Tests**: Continuous operation and edge cases

### Debugging Infrastructure

**Logging System**:
```python
DEBUG = True

def log_debug(message, category="GENERAL"):
    if DEBUG:
        timestamp = utime.ticks_ms()
        print(f"[{timestamp}] {category}: {message}")
```

**Performance Monitoring**:
- Execution time measurement
- Memory usage tracking
- Network latency monitoring
- Sensor data validation

## 🔄 Maintenance and Updates

### Code Organization

**File Structure**:
```
/
├── main.py              # Application entry point
├── motor.py             # Core motor control
├── collision.py         # Collision detection
├── calibration.py       # System calibration
├── wifi.py              # Network services
├── display.py           # Display management
├── menu.py              # User interface
├── presets.py           # Height presets
├── accelerometer.py     # Sensor interface
├── acs712.py            # Current sensor
├── buzz_vib.py          # Feedback systems
├── sh1106.py            # Display driver
├── writer.py            # Font rendering
├── songs.py             # Audio patterns
├── rtttl.py             # Music parser
├── freesans20.py        # Font data
└── firacodeBold30.py    # Font data
```

**Coding Standards**:
- PEP 8 Python style guide
- Comprehensive docstrings
- Type hints where applicable
- Error handling for all I/O operations

### Version Management

**Configuration Version Tracking**:
```python
CONFIG_VERSION = "1.0"

def migrate_config(old_config, old_version):
    if old_version < "1.0":
        # Migration logic
        pass
    return updated_config
```

**Over-the-Air Updates** (Future):
- Secure firmware updates via WiFi
- Configuration backup and restore
- Rollback capability for failed updates

---

**Next Steps**: Review [Module Reference](modules.md) for detailed API documentation and [Collision Detection](collision-detection.md) for algorithm implementation details.

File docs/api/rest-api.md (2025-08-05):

# REST API Reference

Complete API documentation for the Smart Sit-Stand Desk Controller. All endpoints support CORS for cross-origin requests.

## 🌐 Base URL

```
http://<pico-ip-address>/
```

Replace `<pico-ip-address>` with your Pico W's IP address on your network.

## 📋 Available Endpoints

### Status & Information

#### Get Current Height
```http
GET /get_height
```

**Description**: Returns the current desk height in real-world units.

**Response:**
```json
{"height": "95.5"}
```

#### Get Min/Max Heights
```http
GET /get_minmax
```

**Description**: Returns the configured minimum and maximum height limits.

**Response:**
```json
{"min": 72.0, "max": 120.0}
```

#### Get Preset Heights
```http
GET /get_presets
```

**Description**: Returns all configured preset heights.

**Response:**
```json
["1: 95.5", "2: 110.0", "3: 115.2"]
```

#### Check Lock Status
```http
GET /islocked
```

**Description**: Returns whether the desk is currently locked.

**Response:**
```json
{"locked": false}
```

### Movement Controls

#### Move Up
```http
GET /forward
```

**Description**: Starts moving the desk upward.

**Response:**
```json
{"status": "ok"}
```

**Note**: Returns `{"status": "nok"}` if desk is locked.

#### Move Down
```http
GET /backward
```

**Description**: Starts moving the desk downward.

**Response:**
```json
{"status": "ok"}
```

**Note**: Returns `{"status": "nok"}` if desk is locked.

#### Stop Movement
```http
GET /stop
```

**Description**: Immediately stops any desk movement.

**Response:**
```json
{"status": "ok"}
```

### Position Control

#### Go to Specific Height
```http
GET /go?height=100.5
```

**Parameters:**
- `height` (required): Target height in real-world units (float)

**Description**: Moves desk to the specified height.

**Response:**
```json
{"status": "ok"}
```

#### Go to Preset
```http
GET /go_preset?preset=1
```

**Parameters:**
- `preset` (required): Preset number (1, 2, or 3)

**Description**: Moves desk to the specified preset position.

**Response:**
```json
{"status": "ok"}
```

**Note**: Returns `{"status": "nok"}` if preset doesn't exist.

### Security Controls

#### Lock Desk
```http
GET /lock
```

**Description**: Locks the desk to prevent all movement.

**Response:**
```json
{"status": "ok"}
```

#### Unlock Desk
```http
GET /unlock
```

**Description**: Unlocks the desk to allow movement.

**Response:**
```json
{"status": "ok"}
```

### Configuration

#### Set Minimum Height
```http
GET /set_min?min=70.0
```

**Parameters:**
- `min` (required): New minimum height limit (float)

**Description**: Updates the minimum height limit.

**Response:**
```json
{"status": "ok"}
```

#### Set Maximum Height
```http
GET /set_max?max=125.0
```

**Parameters:**
- `max` (required): New maximum height limit (float)

**Description**: Updates the maximum height limit.

**Response:**
```json
{"status": "ok"}
```

## 🔧 Response Format

All API endpoints return JSON responses with consistent formatting.

### Success Response
```json
{
  "status": "ok",
  "data": "response_data"
}
```

### Error Response
```json
{
  "status": "nok",
  "error": "Description of error"
}
```

### HTTP Headers

All responses include CORS headers:
```http
Access-Control-Allow-Origin: *
Access-Control-Allow-Methods: *
```

## 📱 Integration Examples

### JavaScript/Fetch API
```javascript
// Get current height
const response = await fetch('http://192.168.1.100/get_height');
const data = await response.json();
console.log('Current height:', data.height);

// Move to specific height
await fetch('http://192.168.1.100/go?height=110.0');

// Go to preset 1
await fetch('http://192.168.1.100/go_preset?preset=1');
```

### Python Requests
```python
import requests

# Get current height
response = requests.get('http://192.168.1.100/get_height')
height = response.json()['height']
print(f'Current height: {height}')

# Move desk up
requests.get('http://192.168.1.100/forward')

# Stop movement after delay
time.sleep(2)
requests.get('http://192.168.1.100/stop')
```

### cURL Commands
```bash
# Get current height
curl http://192.168.1.100/get_height

# Move to sitting height
curl "http://192.168.1.100/go?height=95.0"

# Lock desk
curl http://192.168.1.100/lock

# Check if locked
curl http://192.168.1.100/islocked
```

## 🔒 Security Considerations

### Physical Lock
The `/lock` endpoint provides a software lock that prevents all movement commands. When locked:
- Movement endpoints (`/forward`, `/backward`, `/go`, `/go_preset`) return `{"status": "nok"}`
- Configuration changes are still allowed
- The lock persists across system restarts

### Network Security
- API is accessible to all devices on the local network
- No authentication required (designed for home/office use)
- Consider network-level security (VPN, firewall rules) for enhanced protection

## ⚠️ Important Notes

### Safety
- Always verify desk response before issuing multiple commands
- Use `/stop` endpoint for emergency stops
- Physical buttons override API commands
- Height limits are enforced in software

### Rate Limiting
- No built-in rate limiting
- Avoid rapid successive calls to prevent system overload
- Allow movement commands to complete before issuing new ones

### Error Handling
- Always check response status (`"ok"` vs `"nok"`)
- Handle network timeouts gracefully
- Implement retry logic for critical operations

---

**📞 Support**: For API issues or feature requests, use [GitHub Issues](https://github.com/waliori/RP-pico-sit-stand-firmware/issues)

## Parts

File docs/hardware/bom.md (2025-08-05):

# Bill of Materials (BOM)

Electronic components list for building the Smart Sit-Stand Desk Controller. Quantities reflect actual parts used in the project.

## 📋 Electronic Components List

### Core Electronics

| Component | Description | Quantity Used | Notes |
|---|---|---|---|
| **Raspberry Pi Pico W** | Main microcontroller with WiFi | 1 | Official distributor recommended |
| **BTS7960B H-Bridge** | Motor driver module | 1 | High current capability |
| **37GB555 Geared Motor** | 12V 180RPM DC motor with encoder | 1 | High torque gear reducer |
| **ACS712-30A** | Current sensor module | 1 | 30A Hall effect sensor |
| **ADXL345** | 3-axis accelerometer | 1 | I2C interface |
| **SH1106 OLED** | 128x64 monochrome display | 1 | I2C interface |

### Power & Electrical

| Component | Description | Quantity Used | Notes |
|---|---|---|---|
| **12V Power Supply** | Main power for motor | 1 | Motor power only |
| **3.3V Regulator** | Powers all electronics | 1 | From 12V to 3.3V for logic |
| **Power Connectors** | Various DC connectors | As needed | Power distribution |

### User Interface

| Component | Description | Quantity Used | Notes |
|---|---|---|---|
| **KY-040 Rotary Encoder** | 360° rotary encoder with button | 1 | UI navigation (right side) |
| **KY-040 Rotary Encoder** | 360° rotary encoder (no button) | 1 | Motor position feedback (left side) |
| **Tactile Buttons** | Push buttons for controls | 5 | Up, Down, Preset 1-3 |
| **Mini Rocker Switch** | 2-pin 10x15mm power switch | 1 | ON/OFF functionality |

### Mechanical Components

| Component | Description | Quantity Used | Notes |
|---|---|---|---|
| **Shaft Coupling** | 6mm to 7mm flexible coupler | 1 | D25L30 plum jaw spider |
| **Deep Groove Bearings** | 6000ZZ ball bearings | 2 | High quality |

### Additional Electronics

| Component | Description | Quantity Used | Notes |
|---|---|---|---|
| **Buzzer** | Piezo buzzer (PWM driven) | 1 | Audio feedback |
| **Vibration Motor** | Coin vibration motor 3V | 1 | Haptic feedback |
| **Connection Wires** | Various connection wires | As needed | Prototyping connections |
| **Prototyping Board** | PCB or breadboard | 1 | For permanent assembly |

**Note**: This project uses the Pico W's internal pull-up resistors - no external resistors or capacitors needed for basic operation.

## 💰 Cost Information

**Note**: Costs vary significantly by supplier, region, shipping, and bulk purchasing. The components listed represent the actual electronic parts used in this project. Total project costs will vary based on:

- **Supplier selection** (AliExpress vs Amazon vs DigiKey)
- **Shipping costs** and delivery time preferences
- **Bulk vs individual** purchasing decisions
- **Regional pricing** variations
- **3D printing and mechanical components** (not included in electronics BOM - see CAD files below)
- **Tools and assembly materials** (solder, heat shrink, etc.)

## 🛒 Sourcing Recommendations

### Primary Suppliers

#### Budget-Friendly Options
- **AliExpress**: Best prices for most components (2-4 week shipping)
- **Banggood**: Good selection and reasonable shipping times
- **DHgate**: Bulk quantities available

#### Faster Shipping Options
- **Amazon**: 1-2 day shipping, higher prices
- **DigiKey/Mouser**: Professional grade, excellent for critical components
- **Adafruit/SparkFun**: High-quality breakout boards, educational support

### Regional Suppliers

#### North America
- **DigiKey** (Minnesota, USA)
- **Mouser Electronics** (Texas, USA)
- **Adafruit** (New York, USA)
- **SparkFun** (Colorado, USA)

#### Europe
- **Farnell** (UK/EU)
- **RS Components** (EU)
- **Conrad Electronic** (Germany)

#### Asia-Pacific
- **Element14** (Australia/Asia)
- **Seeed Studio** (China)
- **DFRobot** (China)

## 🔧 Sourcing Strategy

### Phase 1: Essential Components
Start with core electronics to verify functionality:
1. Raspberry Pi Pico W
2. H-Bridge motor driver
3. Power supply and buck converters
4. OLED display
5. Basic breadboard setup

### Phase 2: Motor System
Add mechanical components:
1. Geared motor
2. Shaft coupling
3. Bearings
4. Mounting hardware

### Phase 3: User Interface
Complete the control system:
1. Rotary encoders
2. Mechanical switches
3. Buttons and enclosure

### Phase 4: Sensors & Safety
Final safety and monitoring:
1. Current sensor
2. Accelerometer
3. Additional sensors as needed

## 📦 Bulk Purchase Recommendations

### Typical Purchasing Considerations
- **Resistors**: Often sold in assorted packs
- **Capacitors**: Common values available in variety packs
- **Jumper Wires**: Usually sold in multi-packs
- **Connectors**: May need to buy more than required for project

### Individual Component Items
- **Raspberry Pi Pico W**: From authorized distributor
- **Motor**: Specific torque/speed requirements
- **Power Supply**: Match local electrical standards
- **Coupling**: Exact shaft size matching

## ⚠️ Important Notes

### Safety Considerations
- **Power Supply**: Ensure proper electrical isolation
- **Motor Current**: Verify H-bridge can handle motor load
- **Heat Dissipation**: Consider cooling for high-power components
- **Enclosure**: Use fire-resistant materials for electronics (3D printable designs available)

### Quality Recommendations
- **Critical Components**: Buy from reputable suppliers
  - Raspberry Pi Pico W (avoid clones)
  - Power supply (certified safety ratings)
  - Motor driver (genuine BTS7960B)
- **Test Components**: Before final assembly
- **Backup Parts**: Keep spares of critical components

### Purchasing Tips
1. **Compare Suppliers**: Prices vary significantly between vendors
2. **Check Reviews**: Verify component quality, especially for critical parts
3. **Consider Shipping**: Factor delivery costs and timeframes
4. **Local Availability**: Check electronics stores for immediate needs

## 📋 Pre-Assembly Checklist

Before starting your build:

- [ ] **All components received** and verified against BOM
- [ ] **Power supply tested** and voltage verified
- [ ] **Workspace prepared** with proper tools
- [ ] **Documentation reviewed** including wiring diagrams
- [ ] **Safety equipment ready** (safety glasses, proper lighting)
- [ ] **Backup components** for critical parts available

## 🔗 Useful Links

### 🎨 **3D Models & CAD Files** (Fully Open Source)
- **📐 Complete CAD Models**: [OnShape CAD Document](https://cad.onshape.com/documents/f9483c31494feda60f507100/w/67832ca84d886d2bfa4006b1/e/62aed646cd76d0a16e7ccfc5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) - Fully editable CAD format
- **🖨️ 3D Printable Parts**: All enclosures, mounts, and brackets available in native CAD format
- **📝 Mechanical Drawings**: Dimensions and tolerances included in CAD

### 📚 Additional Resources
- **Schematic Diagrams**: [Circuit Diagrams](circuit-diagrams.md)
- **Assembly Guide**: [Hardware Assembly](assembly.md)
- **Build Video**: [🎬 YouTube Documentary](https://www.youtube.com/watch?v=PKzvHBzcGJ4)

---

**💡 Tip**: Start with a breadboard prototype to verify all connections before committing to a permanent PCB or enclosure assembly. All 3D printable parts are available in the OnShape CAD document above.

**⚠️ Important**: This BOM lists only electronic components actually used in the project. Costs are not provided as they vary significantly by supplier, region, and purchasing decisions. Always verify current pricing and component specifications before ordering.

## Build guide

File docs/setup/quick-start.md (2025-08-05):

# Quick Start Guide

Get your Smart Sit-Stand Desk Controller running with this setup guide.

🎬 **[Watch the Build Journey](https://www.youtube.com/watch?v=PKzvHBzcGJ4)** - Experience the development adventure and see how to use the finished system.

## ⚡ Prerequisites

- ✅ **Raspberry Pi Pico W** with MicroPython firmware installed
- ✅ **All hardware components** from the [Bill of Materials](../hardware/bom.md)
- ✅ **USB cable** for programming and power
- ✅ **Computer** with Thonny IDE installed

📺 **Pro Tip**: Watch the [build video](https://www.youtube.com/watch?v=PKzvHBzcGJ4) to experience the development journey and see the finished system in action.

## 🔧 Hardware Assembly

Connect components according to the pin configuration in [Hardware Overview](../hardware/overview.md). 

**📐 3D Printed Parts**: All enclosures, mounts, and brackets are available in fully open-source CAD format at [OnShape CAD Document](https://cad.onshape.com/documents/f9483c31494feda60f507100/w/67832ca84d886d2bfa4006b1/e/62aed646cd76d0a16e7ccfc5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).

**Power Connections:**
```
Pico W 3V3 → All electronics (OLED, ADXL345, ACS712, Encoders, Buttons)
Pico W GND → All component grounds
12V Supply → Motor via H-Bridge only
```

**I2C Connections:**
```
GPIO 4 → OLED SDA        GPIO 6 → ADXL345 SDA  
GPIO 5 → OLED SCL        GPIO 7 → ADXL345 SCL
```

**Motor Control:**
```
GPIO 0 → H-Bridge R_PWM
GPIO 1 → H-Bridge L_PWM
GPIO 20 → Position Encoder CLK
GPIO 21 → Position Encoder DT
GPIO 28 → Current Sensor Output
```

**User Interface:**
```
GPIO 13 → UI Encoder Button (right encoder)
GPIO 14 → UI Encoder DT (right encoder)
GPIO 15 → UI Encoder CLK (right encoder)
GPIO 26 → Down Button
GPIO 27 → Up Button
GPIO 9/10/11 → Preset Buttons 1/2/3
```

**Note**: The system uses two separate rotary encoders:
- **Left Encoder** (GPIO 20/21): Motor position feedback only
- **Right Encoder** (GPIO 13/14/15): UI navigation with button

## 💻 Software Installation

### Download and Install

```bash
# Clone the repository
git clone https://github.com/waliori/RP-pico-sit-stand-firmware.git
cd RP-pico-sit-stand-firmware
```

### Upload to Pico W using Thonny

1. Open **Thonny IDE**
2. Configure interpreter: **"MicroPython (Raspberry Pi Pico)"**
3. Upload all `.py` files to the Pico W
4. Run `main.py`

## ⚙️ Initial Configuration

### Height Calibration

When you first power on, the system enters calibration mode:

1. **Move to Highest Position** using manual controls
   - Press and hold the rotary encoder button
   - "Max encoder set" appears on display

2. **Set Real Height Value**
   - Turn rotary encoder to set actual height (e.g., 120.0 cm)
   - Press encoder button to confirm

3. **Move to Lowest Position** using manual controls
   - Press and hold the rotary encoder button
   - "Min encoder set" appears

4. **Set Minimum Height Value**
   - Turn encoder to set actual height (e.g., 72.0 cm)
   - Press encoder button to confirm
   - System saves settings and exits calibration

### WiFi Setup

1. **Access Point Mode**
   - If no saved WiFi, system creates "PicoW" hotspot
   - Password: `waliori123`
   - Connect with phone/laptop

2. **Configuration Portal**
   - Navigate to `192.168.4.1` in web browser
   - Select your WiFi network
   - Enter password and submit
   - System will connect and restart

3. **Find IP Address**
   - Check your router's client list
   - Note the IP address for API access

## ✅ Quick Test

### Verify Operation

1. **Display Test**
   - Current height shows on OLED
   - WiFi icon shows connection status
   - Use rotary encoder to navigate menu

2. **Movement Test**
   - Press Up button (GPIO 27) - desk moves up
   - Press Down button (GPIO 26) - desk moves down
   - Buttons stop movement when released

3. **API Test**
   ```bash
   # Test API connectivity
   curl http://<desk-ip>/get_height
   
   # Should return: {"height": "95.5"}
   ```

### Set Presets

1. **Position 1** (Sitting)
   - Move desk to comfortable sitting height
   - Press Preset 1 button (GPIO 9) for 3 seconds
   - "Preset 1 saved" appears on display

2. **Position 2** (Standing)
   - Move to standing height
   - Press Preset 2 button (GPIO 10) for 3 seconds

3. **Position 3** (Custom)
   - Set any preferred height
   - Press Preset 3 button (GPIO 11) for 3 seconds

**Navigation Note**: Use the right-side rotary encoder (GPIO 13/14/15) for menu navigation. The left-side encoder (GPIO 20/21) provides motor position feedback only.

## 🎯 Menu Navigation

Access settings using the right-side rotary encoder (UI navigation):

**Menu → Configuration → Sleep Timer**: Set display sleep timeout
**Menu → Configuration → Reminder**: Set posture reminder interval
**Menu → WiFi → Toggle API**: Enable/disable web API
**Menu → Lock/Unlock**: Physical lock prevents all movement
**Menu → Collision Reset**: Recalibrate basic safety monitoring

**Important**: Use the right-side encoder for all menu navigation. The left-side encoder is for position feedback only.

## 🌐 Web Interface

Once WiFi is configured:

**Setup Portal**: `http://<desk-ip>/`
**API Endpoints**:
```bash
# Get current height
curl http://<desk-ip>/get_height

# Move to specific height
curl http://<desk-ip>/go?height=100.0

# Go to preset
curl http://<desk-ip>/go_preset?preset=1

# Lock desk
curl http://<desk-ip>/lock
```

## 🚀 Next Steps

**Basic Usage**: You're ready to use your smart desk!

**API Integration**: Review [REST API Reference](../api/rest-api.md)

**Hardware Details**: Check [Hardware Overview](../hardware/overview.md)

---

**🎬 Build Journey**: Experience the complete development adventure in the [YouTube documentary](https://www.youtube.com/watch?v=PKzvHBzcGJ4) to see the system in use.

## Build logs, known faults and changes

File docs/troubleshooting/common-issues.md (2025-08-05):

# Common Issues & Troubleshooting

This guide covers the most frequently encountered problems and their solutions for the Smart Sit-Stand Desk Controller.

## 🚨 Emergency Procedures

### Immediate Safety Actions

**If the desk moves unexpectedly:**
1. **Disconnect power** immediately
2. **Check for physical obstructions**
3. **Verify all connections** before reconnecting
4. **Test manually** before enabling automatic control

**If basic safety monitoring fails:**
1. **Stop using the system** immediately
2. **Check current sensor connections** and calibration
3. **Verify position encoder feedback**
4. **Test position limits** and emergency stop
5. **Note**: Advanced collision detection is under development

## 🔧 Hardware Issues

### Display Problems

#### No Display Output
**Symptoms**: OLED screen remains blank, no startup message

**Diagnostic Steps**:
```bash
# Test I2C communication
mpremote exec "from machine import I2C, Pin; i2c = I2C(0, scl=Pin(5), sda=Pin(4)); print('I2C devices:', [hex(x) for x in i2c.scan()])"
```

**Expected Output**: `I2C devices: ['0x3c']` (SH1106 address)

**Solutions**:
1. **Check power connections**:
   - OLED VCC → Pico 3V3
   - OLED GND → Pico GND
   
2. **Verify I2C wiring**:
   - OLED SDA → GPIO 4
   - OLED SCL → GPIO 5
   
3. **Test with multimeter**:
   - 3.3V present on VCC
   - Continuity on SDA/SCL lines
   
4. **Try different OLED module** (may be defective)

#### Display Shows Corruption
**Symptoms**: Garbled text, random pixels, partial display

**Common Causes**:
- Loose connections
- Interference from motor circuits
- Power supply noise

**Solutions**:
1. **Improve grounding**: Ensure solid ground connections
2. **Check power supply**: Verify stable 3.3V to display
3. **Shorten I2C cables**: Keep connections as short as possible
4. **Shield cables**: Use twisted pair or shielded cables

#### Display Dim or Flickering
**Symptoms**: Display visible but very dim or intermittent

**Solutions**:
1. **Check power supply voltage**: Should be stable 3.3V
2. **Reduce I2C frequency**: Change to 100kHz in `display.py`
3. **Check connections**: Verify SDA and SCL wiring (Pico W has internal pull-ups)

### Motor Control Issues

#### Motor Doesn't Move
**Symptoms**: No movement when buttons pressed, no motor sound

**Diagnostic Steps**:
```bash
# Test PWM output
mpremote exec "from machine import Pin, PWM; pwm = PWM(Pin(0)); pwm.freq(1000); pwm.duty_u16(32768); print('PWM active')"
```

**Check List**:
1. **Power supply**: H-bridge has adequate voltage/current
2. **PWM signals**: GPIO 0 and 1 showing PWM output
3. **Enable signals**: H-bridge enable pins connected
4. **Motor connections**: Wiring to linear actuator correct
5. **Position feedback**: Encoder properly connected

**Solutions**:
1. **Verify H-bridge wiring**:
   ```
   Pico GPIO 0 → H-Bridge IN1 (Forward PWM)
   Pico GPIO 1 → H-Bridge IN2 (Reverse PWM)
   H-Bridge OUT1/OUT2 → Motor terminals
   ```

2. **Test motor directly**: Apply DC voltage to motor terminals
3. **Check current sensor**: Ensure not causing interference
4. **Verify enable signals**: Some H-bridges need enable pins

#### Motor Runs Continuously
**Symptoms**: Motor won't stop, ignores commands

**Immediate Action**: **Disconnect power immediately**

**Diagnostic Steps**:
1. **Check encoder connections**: GPIO 20, 21 for position feedback
2. **Verify encoder signals**: Should see pulses when moved manually
3. **Test position counter**: 
   ```bash
   mpremote exec "print('Current position:', motor.counter)"
   ```

**Solutions**:
1. **Reconnect encoder**: Ensure CLK and DT are correctly wired
2. **Check encoder power**: 3.3V or 5V as required
3. **Check wiring**: Verify encoder signal connections (Pico W has internal pull-ups)
4. **Verify encoder type**: Incremental quadrature encoder required

#### Motor Jerky Movement
**Symptoms**: Stuttering, vibration, irregular speed

**Causes**:
- Poor PWM frequency
- Power supply issues
- Mechanical binding

**Solutions**:
1. **Adjust PWM frequency**: Try 16kHz (current) or 20kHz
2. **Improve power supply**: Better regulation and stable voltage
3. **Check mechanical coupling**: Ensure smooth mechanical operation
4. **Reduce acceleration**: Modify ramp-up rate in code

### Sensor Problems

#### Current Sensor Giving Wrong Readings
**Symptoms**: Collision detection too sensitive or not working

**Diagnostic Steps**:
```bash
# Test current sensor
mpremote exec "from machine import ADC; adc = ADC(28); print('Raw ADC:', adc.read_u16())"
```

**Expected Values**:
- No current: ~32768 (2.5V with ±5A sensor)
- With current: Proportional to load

**Solutions**:
1. **Check sensor type**: Ensure ACS712-30A (66mV/A sensitivity)
2. **Verify connections**:
   - VCC → 5V (not 3.3V)
   - VIOUT → GPIO 28 (may need voltage divider)
   - GND → Common ground

3. **Calibrate zero point**: 
   ```python
   # Add to acs712.py initialization
   self.zero_offset = 2.29  # Measure actual zero voltage
   ```

4. **Add filtering**: Software average over multiple readings

#### Accelerometer Not Responding
**Symptoms**: Collision detection not working, no sensor data

**Diagnostic Steps**:
```bash
# Test I2C communication
mpremote exec "from machine import I2C, Pin; i2c = I2C(1, scl=Pin(7), sda=Pin(6)); print('Devices:', [hex(x) for x in i2c.scan()])"
```

**Expected Output**: `Devices: ['0x53']` (ADXL345 address)

**Solutions**:
1. **Check I2C wiring**:
   - SDA → GPIO 6
   - SCL → GPIO 7
   - VCC → 3.3V
   - GND → Common ground

2. **Verify I2C address**: ADXL345 should appear at 0x53
3. **Test with different sensor**: Component may be defective
4. **Check I2C connections**: Verify SDA and SCL wiring (internal pull-ups enabled)

#### Position Encoder Errors
**Symptoms**: Wrong height readings, drift, jumping values

**Important**: Position feedback uses the LEFT encoder (GPIO 20/21), not the right UI encoder.

**Diagnostic Steps**:
1. **Test left encoder manually**: Turn shaft, check for pulses
2. **Verify wiring**: Left encoder CLK → GPIO 20, DT → GPIO 21
3. **Check mechanical coupling**: Left encoder should turn with motor
4. **Test position counter**:
   ```bash
   mpremote exec "print('Current encoder position:', motor.counter)"
   ```

**Solutions**:
1. **Clean left encoder contacts**: Remove dust/debris from position encoder
2. **Tighten mechanical coupling**: Ensure no slippage on motor shaft
3. **Check left encoder wiring**: Verify CLK and DT connections (internal pull-ups enabled)
4. **Check encoder type**: Incremental quadrature required
5. **Verify encoder separation**: Ensure position encoder (left) is not confused with UI encoder (right)

## 💻 Software Issues

### WiFi Connection Problems

#### Cannot Connect to Saved Networks
**Symptoms**: WiFi shows connected networks but fails to connect

**Diagnostic Steps**:
```bash
# Check saved networks
mpremote exec "import json; print(json.load(open('saved_wifi.json')))"

# Test network scanning
mpremote exec "import network; wlan = network.WLAN(network.STA_IF); wlan.active(True); print([net[0].decode() for net in wlan.scan()])"
```

**Solutions**:
1. **Verify credentials**: Delete and re-add network credentials
2. **Check signal strength**: Move closer to router
3. **Reset network config**: Delete `saved_wifi.json` file
4. **Check network compatibility**: 2.4GHz only, WPA2/WPA3

#### Access Point Mode Not Working
**Symptoms**: Cannot find "PicoW" hotspot

**Solutions**:
1. **Check AP configuration**:
   ```python
   # In wifi.py
   self.apssid = "PicoW"
   self.appassword = "waliori123"
   ```

2. **Verify AP activation**:
   ```bash
   mpremote exec "import network; ap = network.WLAN(network.AP_IF); ap.active(True); print('AP active:', ap.active())"
   ```

3. **Try different device**: Some phones/laptops have WiFi compatibility issues

#### Web Interface Not Accessible
**Symptoms**: Cannot reach 192.168.4.1 or device IP

**Diagnostic Steps**:
1. **Ping test**: `ping 192.168.4.1` (AP mode) or device IP
2. **Port scan**: `nmap -p 80 <device-ip>`
3. **Check web server**: 
   ```bash
   mpremote exec "print('Web server running:', wifi.server)"
   ```

**Solutions**:
1. **Restart web server**: Power cycle device
2. **Check firewall**: Disable temporarily on client device
3. **Try different browser**: Some browsers cache aggressively
4. **Use IP address**: Instead of hostname

### Menu System Issues

#### Rotary Encoder Not Working
**Symptoms**: Cannot navigate menu, encoder doesn't respond

**Important**: This system uses TWO separate rotary encoders:
- **Right Encoder** (GPIO 13/14/15): UI navigation with button
- **Left Encoder** (GPIO 20/21): Motor position feedback only

**Diagnostic Steps for UI Navigation (Right Encoder)**:
```bash
# Test UI encoder inputs
mpremote exec "from machine import Pin; clk = Pin(15, Pin.IN, Pin.PULL_UP); dt = Pin(14, Pin.IN, Pin.PULL_UP); sw = Pin(13, Pin.IN, Pin.PULL_UP); print('UI Encoder - CLK:', clk.value(), 'DT:', dt.value(), 'SW:', sw.value())"
```

**Diagnostic Steps for Position Feedback (Left Encoder)**:
```bash
# Test position encoder inputs
mpremote exec "from machine import Pin; clk = Pin(20, Pin.IN, Pin.PULL_UP); dt = Pin(21, Pin.IN, Pin.PULL_UP); print('Position Encoder - CLK:', clk.value(), 'DT:', dt.value())"
```

**Expected Values**:
- All should read 1 (high) when not pressed/turned
- Values should change when encoder moved

**Solutions**:
1. **Check UI encoder wiring (right side)**:
   - CLK → GPIO 15
   - DT → GPIO 14  
   - SW → GPIO 13

2. **Check position encoder wiring (left side)**:
   - CLK → GPIO 20
   - DT → GPIO 21

3. **Enable pull-ups**: Already done in code, verify hardware
4. **Test encoders mechanically**: Both should click when turned
5. **Try different encoders**: Components may be defective

#### Menu Freezes or Unresponsive
**Symptoms**: Display shows menu but doesn't respond to inputs

**Solutions**:
1. **Restart system**: Power cycle device
2. **Check thread locks**: May be deadlocked
3. **Clear display lock**:
   ```bash
   mpremote exec "import _thread; sLock = _thread.allocate_lock(); sLock.release()"
   ```

### Calibration Problems

#### Height Calibration Fails
**Symptoms**: Cannot complete calibration, wrong height values

**Solutions**:
1. **Clear previous calibration**:
   ```bash
   # Delete configuration files
   mpremote fs rm settings.json
   mpremote fs rm state.json
   ```

2. **Manual encoder test**:
   ```bash
   mpremote exec "print('Encoder position:', motor.counter)"
   ```

3. **Check encoder range**: Should change significantly between limits

#### Basic Safety Monitoring Issues
**Symptoms**: Unexpected stops, false safety triggers

**Solutions**:
1. **Check current sensor calibration**: Verify ACS712 connections and zero point
2. **Verify position limits**: Ensure encoder feedback is accurate
3. **Test individual sensors**: Isolate and test each safety component
4. **Update configuration**: Adjust safety thresholds in settings.json
5. **Future Enhancement**: Advanced PCA-based collision detection is under development

## 🔍 Diagnostic Tools

### Built-in Diagnostics

#### System Status Check
```bash
mpremote exec "
import os, sys, gc
print('MicroPython:', sys.implementation)
print('Available memory:', gc.mem_free())
print('Files:', os.listdir())
print('System ready')
"
```

#### Sensor Reading Test
```bash
mpremote exec "
# Test all sensors
from machine import I2C, Pin, ADC
import accelerometer, acs712

# I2C devices
i2c0 = I2C(0, scl=Pin(5), sda=Pin(4))
i2c1 = I2C(1, scl=Pin(7), sda=Pin(6))
print('I2C0 devices:', [hex(x) for x in i2c0.scan()])
print('I2C1 devices:', [hex(x) for x in i2c1.scan()])

# Current sensor
adc = ADC(28)
print('Current sensor raw:', adc.read_u16())

# Accelerometer
try:
    accel = accelerometer.Accelerometer(Pin(6), Pin(7), 400000)
    print('Accelerometer:', accel.read_accel_data())
except:
    print('Accelerometer error')
"
```

#### Network Diagnostics
```bash
mpremote exec "
import network
wlan = network.WLAN(network.STA_IF)
print('WiFi active:', wlan.active())
print('Connected:', wlan.isconnected())
if wlan.isconnected():
    print('IP config:', wlan.ifconfig())
print('Scan results:', len(wlan.scan()), 'networks found')
"
```

### External Tools

#### Network Analysis
```bash
# Find device on network
nmap -sn 192.168.1.0/24 | grep -B2 "Raspberry Pi"

# Port scan
nmap -p 80,8080 <device-ip>

# HTTP test
curl -v http://<device-ip>/get_height
```

#### Serial Monitoring
```bash
# Linux/Mac
screen /dev/ttyACM0 115200

# Windows (PowerShell)
python -m serial.tools.miniterm COM3 115200

# View continuous output
tail -f /dev/ttyACM0
```

## 🛠️ Recovery Procedures

### Factory Reset

#### Software Reset
```bash
# Delete all configuration files
mpremote fs rm settings.json
mpremote fs rm presets.json  
mpremote fs rm saved_wifi.json
mpremote fs rm state.json

# Restart system
mpremote reset
```

#### Complete Reinstall
```bash
# Backup any custom files first
mpremote fs cp settings.json settings_backup.json

# Remove all files
mpremote fs rm *.py
mpremote fs rm *.json

# Re-upload firmware
mpremote fs cp *.py :

# Reset and restart
mpremote reset
```

#### Hardware Reset
1. **Hold BOOTSEL button** while connecting USB
2. **Copy UF2 firmware** to mounted drive
3. **Reconnect normally** and re-upload code

### Emergency Safe Mode

If system becomes completely unresponsive:

1. **Create minimal main.py**:
   ```python
   # minimal_main.py
   print("Safe mode - system ready")
   from machine import Pin
   led = Pin("LED", Pin.OUT)
   led.on()  # LED on indicates safe mode
   ```

2. **Upload and test**:
   ```bash
   mpremote fs cp minimal_main.py main.py
   mpremote reset
   ```

3. **Gradually add functionality** back until issue is identified

## 📞 Getting Help

### Information to Collect

Before seeking help, gather:

1. **Hardware configuration**: Components used, wiring details
2. **Software version**: Git commit hash or download date
3. **Error messages**: Complete error text from console
4. **System status**: Output of diagnostic commands above
5. **Steps to reproduce**: Exact sequence that causes issue

### Debug Logs

Enable detailed logging:
```python
# Add to main.py
DEBUG = True

def log_debug(message):
    if DEBUG:
        print(f"[{time.ticks_ms()}] DEBUG: {message}")
```

### Community Support

- **GitHub Issues**: Report bugs and request features
- **GitHub Discussions**: Ask questions and share solutions
- **Documentation**: Check other wiki pages for detailed info

### Professional Support

For commercial or safety-critical applications:
- Consult qualified electricians for power systems
- Consider professional mechanical integration
- Implement additional safety systems as required

---

**Remember**: When in doubt, prioritize safety. Disconnect power and seek help rather than risk injury or equipment damage.

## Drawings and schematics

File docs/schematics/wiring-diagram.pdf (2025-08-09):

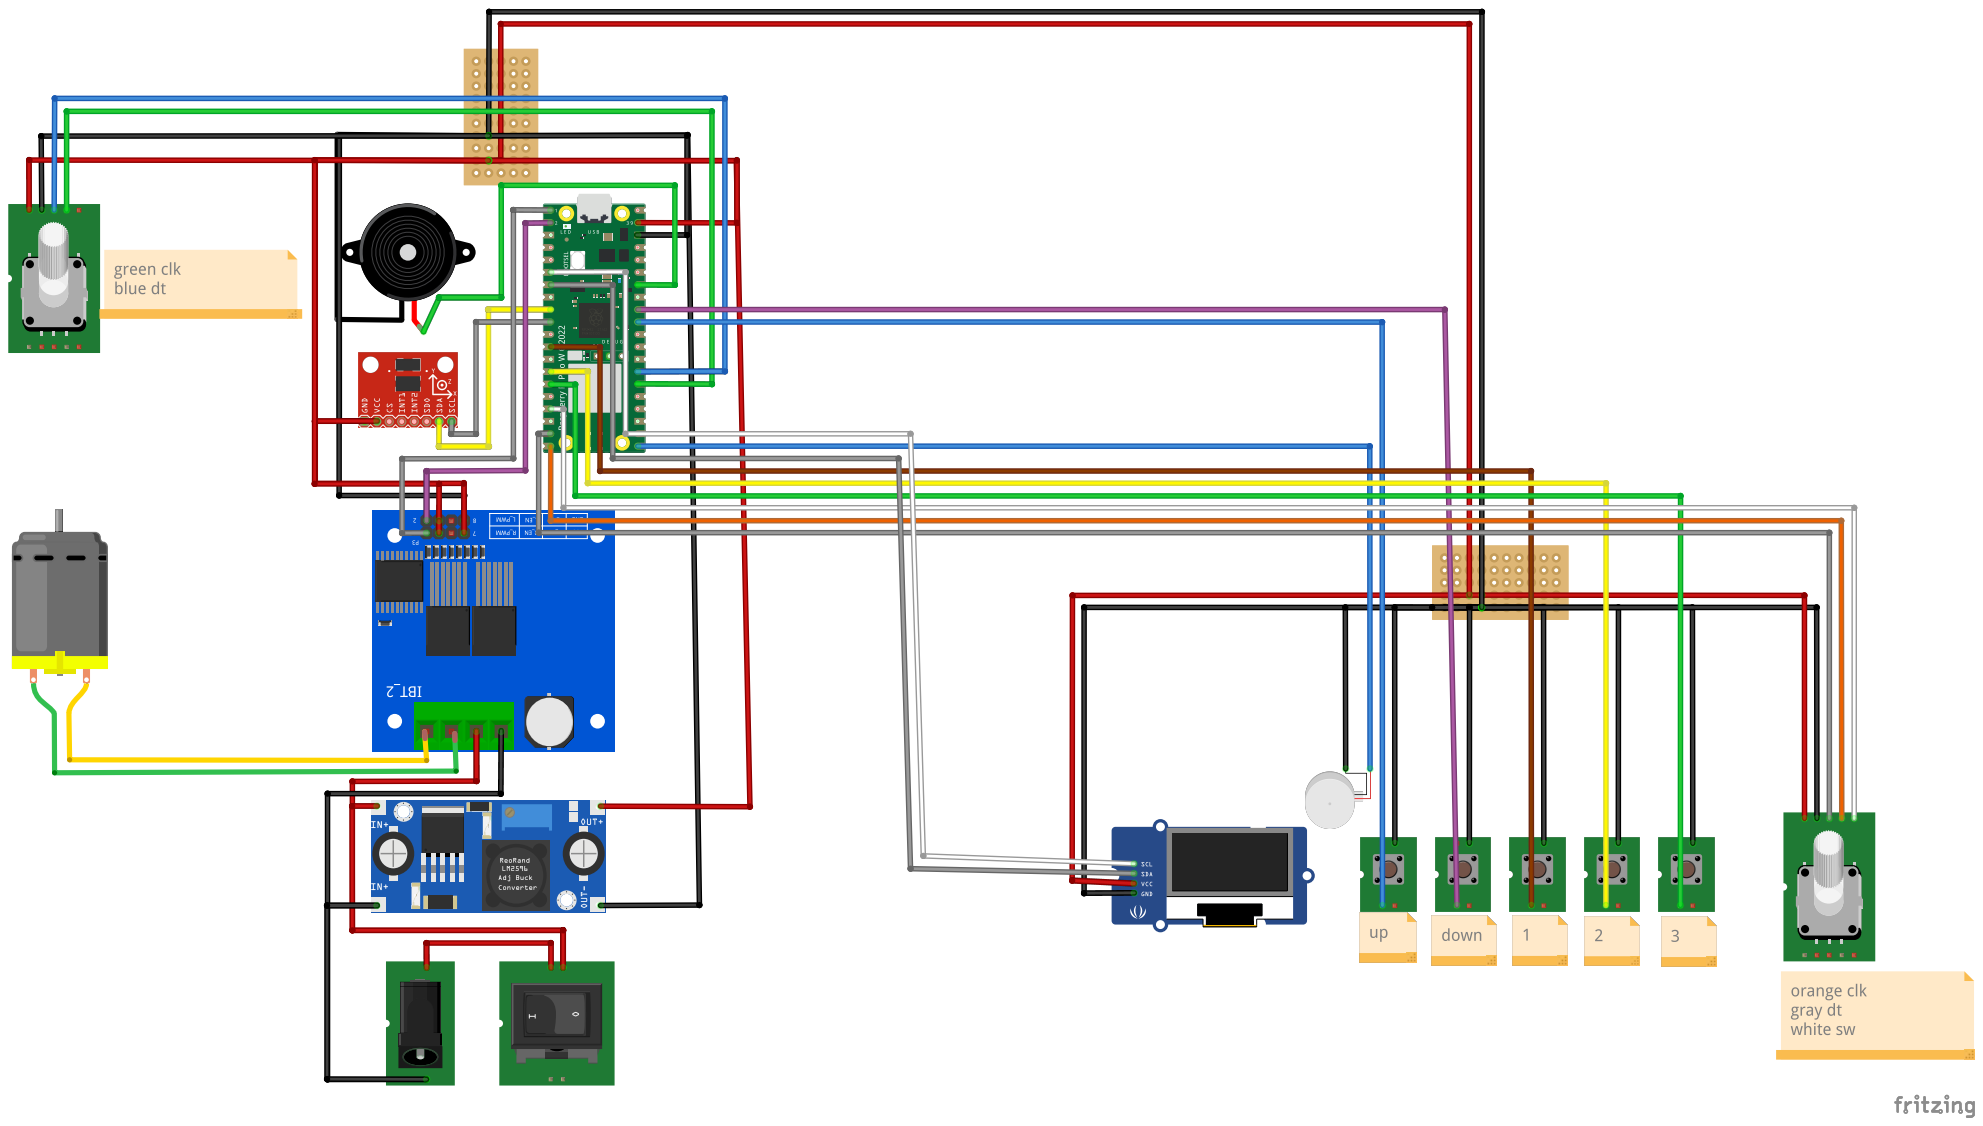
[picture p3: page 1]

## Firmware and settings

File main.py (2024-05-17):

"""
author: waliori
"""
# from machine import WDT

from setup import *
import _thread
from abutton import Pushbutton
import uasyncio
from time import time
import machine
# import math
print("==============")
print("imports done")

# wdt = WDT(timeout=8388)  # enable it with a timeout of 2s
# Motor Section
#TODO modifier go height to calculate current height + wanted height < max
#TODO add acceleration + position to know if impact        
current_m = ".."
menu_list = ["..", "WiFi","Configuration", "Lock Unlock", "Show Presets", "Show min/max", "Collision Reset", "Factory Reset"]
conf_menu = ["Go back","Sleep after","Set min/max", "Stand reminder","Vibration", "Sound"]
sound_menu = ["Back to Conf","On/Off","Melodies"]
menu = ["Back to Wifi","Connect","Forget"]
mm = ["Back to Conf","Min","Max"]
chosen_wf = ""



pb_up = Pushbutton(up_button, suppress=True)
pb_down = Pushbutton(down_button, suppress=True)
pb_switch = Pushbutton(button_pin, suppress = True)

pb_one = Pushbutton(one_button, suppress=True)
pb_two = Pushbutton(two_button, suppress=True)
pb_three = Pushbutton(three_button, suppress=True)

# timeo = 0
start_tm = time()
start_tm_rem = time()

button_pressed = False
current_melody_id = None

loop = asyncio.get_event_loop()

print("initial setup done -------")
def move_motor(button,calibration=False):
    motorO.move_motor(button,up_button,outA,outB,calibrationO.min_encoder, calibrationO.max_encoder, calibration )          
            
                       
# Menu handeling Section

def show_menu(menu):
    sLock.acquire()      
    menuO.menu_state = True
    menuO.reset_state = False
    menuO.presets_state = False
    calibrationO.system_idle = False
    line = 1
    displayO.show_menu(menu, line, menuO.highlight, menuO.shift,menuO.total_lines,"Menu",wifiO.wifi,wifiO.aps)
    sLock.release()
    
def disconnect():
    wifiO.disconnect()
    go_home()
    
def forget_wf(wifi):
    sLock.acquire()
    displayO.oled.fill(0)
    displayO.show_header(wifi,wifiO.wifi,wifiO.aps)
    displayO.show_frame()
    displayO.text_frame(f"Forget {wifi}, do you confirm?")
    menuO.forget_w_state = True
    menuO.wc_state = False
    menuO.wc_c_state = False
    sLock.release()
    
def forget_wifi(wifi):
#     print(wifi)
    wifiO.forget_wifi(wifi)
    go_home()
    
def connect_c_wifi(wifi):
#     sLock.acquire()
    connected = wifiO.connect(wifi,wifiO.saved_json[wifi])
#     sLock.release()
    if connected:
        toggle_server(loop,'start')
        go_home()
    else:
        displayO.oled.fill(0)
        displayO.show_frame()
        menuO.presets_state = True
        menuO.menu_state = False
        calibrationO.system_idle = False
        displayO.text_frame("Could not connect, try again")
        displayO.show_header("WiFi",wifiO.wifi,wifiO.aps)
        displayO.oled.show()
        asyncio.sleep(10)
        wifi_menu()

def set_sleep():
    sLock.acquire()
    menuO.slp_state = True
    menuO.rem_state =False
    preset_list = ["Turn KNOB to", "set time sleep"]
    displayO.show_static_frame(preset_list,len(preset_list))
    displayO.show_header("Sleep",wifiO.wifi,wifiO.aps)
    displayO.oled.show()
    sLock.release()
    
def stand_rem():
    sLock.acquire()
    menuO.rem_state = True
    menuO.slp_state =False
    preset_list = ["Turn KNOB to", "set posture reminder"]
    displayO.show_static_frame(preset_list,len(preset_list))
    displayO.show_header("Reminder",wifiO.wifi,wifiO.aps)
    displayO.oled.show()
    sLock.release()
    
def config_menu():
    global conf_menu
    menuO.highlight = 1
    menuO.menu_state = False
    calibrationO.system_idle = False
    sLock.acquire()    
    line = 1    
    displayO.oled.fill(0)
    displayO.show_frame()
    menuO.cf_state = True #mimic menustate
    menuO.cf_h_state = False
    menuO.cf_s_state = False
    menuO.wc_state = False
    menuO.wc_c_state = False
    menuO.s_w_state = False
    menuO.presets_state = False
    displayO.show_menu(conf_menu, line, menuO.highlight, menuO.shift,min(len(conf_menu),menuO.total_lines),"Config",wifiO.wifi,wifiO.aps)
    sLock.release()

def wifi_menu():
    menuO.highlight = 1
    menuO.menu_state = False
    calibrationO.system_idle = False
    sLock.acquire()    
    line = 1    
    displayO.oled.fill(0)
    displayO.show_frame()
    if wifiO.saved_json:
        menuO.wc_state = True #mimic menustate
        menuO.wc_c_state = False
        menuO.s_w_state = False
        menuO.cf_state = False
        menuO.presets_state = False
        wifiO.nearby_wifis()
        displayO.show_menu(wifiO.nearby, line, menuO.highlight, menuO.shift,min(len(wifiO.nearby),menuO.total_lines),"Wifi",wifiO.wifi,wifiO.aps)
    else:
        menuO.presets_state = True
        displayO.text_frame("Start AP, PicoW:waliori123 then visit 192.168.4.1")
        displayO.show_header("WiFi",wifiO.wifi,wifiO.aps)
        displayO.oled.show()
    sLock.release()

def connect_wifi():
    menuO.highlight = 1
    menuO.menu_state = False
    calibrationO.system_idle = False
    line = 1    
    displayO.oled.fill(0)
    displayO.show_frame()
    if wifiO.saved_json:
        menuO.wc_state = True #mimic menustate
        menuO.wc_c_state = False #mimic menustate
        menuO.cf_state = False
        menuO.s_w_state = False
        menuO.presets_state = False
        displayO.show_menu(wifiO.nearby, line, menuO.highlight, menuO.shift,min(len(wifiO.nearby),menuO.total_lines),"Wifi",wifiO.wifi,wifiO.aps)
    else:
        menuO.presets_state = True
        displayO.text_frame("Connect to PicoW:waliori123 then visit 192.168.4.1")
        displayO.show_header("WiFi",wifiO.wifi,wifiO.aps)
        displayO.oled.show()

#     menuO.wc_state = True #mimic menustate

#     menuO.presets_state = True


def c_wifi(wifi):
    global menu, chosen_wf
    menuO.highlight = 1
    menuO.wc_c_state = True #mimic menustate
    menuO.wc_state = False
    menuO.s_w_state = False
    menuO.cf_state = False
    menuO.presets_state = False
    chosen_wf = wifi
    line = 1  
    displayO.oled.fill(0)
    displayO.show_frame()  
    displayO.show_menu(menu, line, menuO.highlight, menuO.shift,min(len(menu),menuO.total_lines),wifi,wifiO.wifi,wifiO.aps)



async def a_c_melody(melody,melody_id):
    global button_pressed
    buzzvibO.play_tone(0, 0)
    if melody != "Back to Sounds":
        tune = RTTTL(songs.find(melody))
        try:
            buzzvibO.stop_flag = False
            button_pressed = False
            for freq, msec in tune.notes():
                if melody_id != current_melody_id or button_pressed or buzzvibO.stop_flag:
                    buzzvibO.play_tone(0, 0)  # Stop playing
                    break
                buzzvibO.play_tone(freq, msec)
                await asyncio.sleep(msec / 30000)  # Yield control to the event loop
        except KeyboardInterrupt:
            buzzvibO.play_tone(0, 0)


def c_melody(melody):
    global loop, current_melody_id
    melody = melody.replace("-> ", "")
    current_melody_id = id(melody)
    loop.create_task(a_c_melody(melody,current_melody_id))

    
def ch_melody(melody):    
    buzzvibO.set_song(melody)
    sound_m()                                                                                                                                                                               

    
def go_home():    
    sLock.acquire()
    buzzvibO.play_tone(0, 0)
    buzzvibO.stop()
    calibrationO.system_idle = True
    menuO.s_w_state = False
    menuO.wc_state = False
    menuO.wc_c_state = False
    menuO.cf_state = False
    menuO.cf_h_state=False
    menuO.cf_s_state = False
    menuO.cf_mel_state = False
    menuO.min_state = False
    menuO.max_state = False
    menuO.presets_state = False
    menuO.slp_state=False
    menuO.forget_w_state = False
    menuO.rem_state = False    
    menuO.go_home(wifiO.wifi,wifiO.aps,calibrationO.real_height,motorO.counter)
    sLock.release()

    
def go_back():
    global current_m, menu_list
#     print(current_m)
    if current_m in ["Show IP","Back to Wifi"]:
        current_m = "WiFi"
        wifi_menu()
    elif current_m in ["WiFi","Lock Unlock", "Show Presets", "Show min/max", "Collision Reset", "Factory Reset","Configuration","Go back"]:
        show_menu(menu_list)
    elif current_m in ["Sleep after","Back to Conf", "Vibration"]:
        current_m = "Configuration"
        config_menu()    
    elif current_m == "..":
        go_home()

def stop_ap():
    wifiO.stop()
    go_home()

def start_ap():#when up and restart cannot connect wifi 
    displayO.clear_frame()
    displayO.text_frame("Connect to PicoW:waliori123 then visit 192.168.4.1")
    utime.sleep(2)
    go_home()
    loop.create_task(wifiO.apserver(calibrationO.real_height,motorO.counter))

def list_saved_wifi():
    menuO.highlight = 1
    menuO.s_w_state = True
    menuO.wc_state = False
    menuO.wc_c_state = False
    saved_wifis = wifiO.saved_json
    w_l = list(saved_wifis.keys())
    print(w_l,wifiO.ssid)
    if wifiO.wlan.isconnected():
        w_l[w_l.index(wifiO.ssid)] = f"->{wifiO.ssid}"
    line = 1  
    displayO.oled.fill(0)
    displayO.show_frame()  
    displayO.show_menu(w_l, line, menuO.highlight, menuO.shift,min(len(w_l),menuO.total_lines),"Wifis",wifiO.wifi,wifiO.aps)
    
def set_minmax():
    sLock.acquire()
    global mm
    menuO.highlight = 1
    menuO.cf_h_state =True
    menuO.cf_state = False    
    line = 1  
    displayO.oled.fill(0)
    displayO.show_frame()  
    displayO.show_menu(mm, line, menuO.highlight, menuO.shift,min(len(mm),menuO.total_lines),"min/max",wifiO.wifi,wifiO.aps)
    sLock.release()

def min_m():
    sLock.acquire()
    menuO.min_state = True
    menuO.max_state = False
    preset_list = ["Turn KNOB to", "set min height"]
    displayO.show_static_frame(preset_list,len(preset_list))
    displayO.show_header("Min",wifiO.wifi,wifiO.aps)
    displayO.oled.show()
    sLock.release()
    
def set_min(height):
    menuO.min_state = False
    calibrationO.set_min(height)
    set_minmax()

def set_max(height):
    menuO.max_state = False
    calibrationO.set_max(height)
    set_minmax()
    
def max_m():
    sLock.acquire()
    menuO.max_state = True
    menuO.min_state = False
    preset_list = ["Turn KNOB to", "set max height"]
    displayO.show_static_frame(preset_list,len(preset_list))
    displayO.show_header("Max",wifiO.wifi,wifiO.aps)
    displayO.oled.show()
    sLock.release()

def toggle_vibration():
    sLock.acquire()
    buzzvibO.toggle_vibration()  # Toggle vibration state
    displayO.oled.fill(0)
    
    if buzzvibO.vibration:
        buzzvibO.vibrat.value(1)  # Vibrate when vibration is on
        lock = ["Vibration", "ON"]
    else:
        buzzvibO.vibrat.value(0)
        lock = ["Vibration", "OFF"]

    displayO.show_frame()
    displayO.show_static_frame(lock, len(lock))
    utime.sleep(1)
    buzzvibO.vibrat.value(0)
    sLock.release()
    displayO.oled.fill(0)
    config_menu()

def toggle_sound():
    sLock.acquire()
    menuO.cf_st_state =True 
    buzzvibO.toggle_sound()  # Toggle vibration state
    displayO.oled.fill(0)
    
    if buzzvibO.sound:
        buzzvibO.buzzer.duty_u16(440)  # Vibrate when vibration is on
        lock = ["Sound", "ON"]
    else:
        buzzvibO.buzzer.duty_u16(0)
        lock = ["Sound", "OFF"]

    displayO.show_frame()
    displayO.show_static_frame(lock, len(lock))
    utime.sleep(1)
    buzzvibO.buzzer.duty_u16(0)
    sLock.release()
    displayO.oled.fill(0)
    sound_m()
    
    
   
def sound_m():
#     sLock.acquire() 
    menuO.highlight = 1
    menuO.shift = 0
    menuO.cf_s_state =True
    menuO.cf_state = False
    menuO.cf_mel_state = False
    menuO.cf_st_state =False
    line = 1  
    displayO.oled.fill(0)
    displayO.show_frame()  
    displayO.show_menu(sound_menu, line, menuO.highlight, menuO.shift,min(len(sound_menu),menuO.total_lines),"Sound",wifiO.wifi,wifiO.aps)
#     sLock.release() 
#     toggle_sound()
   
   
def melodies_m():
    global button_pressed
    button_pressed = False
    menuO.highlight = 1
    menuO.shift = 0
    menuO.cf_mel_state =True   
    line = 1  
    displayO.oled.fill(0)
    displayO.show_frame()

    displayO.show_menu(buzzvibO.songs, line, menuO.highlight, menuO.shift,min(len(buzzvibO.songs),menuO.total_lines),"Melodies",wifiO.wifi,wifiO.aps)

def toggle_api():
    sLock.acquire()
    displayO.oled.fill(0)
    if wifiO.server:
        lock = ["API", "Off"]
        loop.create_task(wifiO.serve("stop"))
    else:
        lock = ["API", "On"]
        loop.create_task(wifiO.serve("start"))
    displayO.show_frame()
    displayO.show_static_frame(lock, len(lock))    
    utime.sleep(1)    
    sLock.release()
    displayO.oled.fill(0)
    wifi_menu()


def launch(item):
    global current_m, chosen_wf, button_pressed
    button_pressed = True
    current_m = item

    actions = {
        "..": go_home,
        "Show Presets": show_presets,
        "Factory Reset": confirm_reset,
        "Show min/max": show_calibration,
        "Show IP": show_ip,
        "Lock Unlock": lock_unlock,
        "WiFi": wifi_menu,
        "Collision Reset": confirm_reset_collision,
        "Disconnect": disconnect,
        "Scan again": wifi_menu,
        "Go back": go_back,
        "Back to Wifi": go_back,
        "Configuration": config_menu,
        "Sleep after": set_sleep,
        "Start AP": start_ap,
        "Stop AP": stop_ap,
        "Connect": connect_c_wifi,
        "Forget": forget_wf,
        "Saved WiFi": list_saved_wifi,
        "Set min/max": set_minmax,
        "Back to Conf": go_back,
        "Min": min_m,
        "Max": max_m,
        "Stand reminder": stand_rem,
        "Vibration": toggle_vibration,
        "Sound": sound_m,
        "On/Off": toggle_sound,
        "Melodies": melodies_m,
        "Toggle API": toggle_api
    }

    def extend_actions(prefix, keys, action):
        for key in keys:
            actions[prefix + key] = lambda item=key: action(item)

    if wifiO.saved_json:
        keys = list(wifiO.saved_json.keys())
        extend_actions("", keys, c_wifi)
        extend_actions("->", keys, c_wifi)

    extend_actions("", buzzvibO.songs, ch_melody)
    extend_actions("->", buzzvibO.songs, ch_melody)

    def default_action(): 
        print("No action defined for this item")

    action = actions.get(item, default_action)
    
    special_cases = ["Connect", "Forget"]
    if item in special_cases:
        action(chosen_wf)
    else:
        action()
    



# real height facilitator adding 10s and 100s when rotating the rotary encoder
def toggle_01():
    sLock.acquire()
    calibrationO._01 = False if calibrationO._01 else True
    calibrationO._100 = False
    calibrationO._10 = False
    sLock.release()

def toggle_10():
    sLock.acquire()
    calibrationO._10 = False if calibrationO._10 else True
    calibrationO._100 = False
    calibrationO._01 = False
    sLock.release()
        
def toggle_100():
    sLock.acquire()
    calibrationO._100 = False if calibrationO._100 else True
    calibrationO._10 = False
    calibrationO._01 = False
    sLock.release()

# presets

def go_to_preset(preset):
    if presetsO.get_preset(preset):
        p = presetsO.get_preset(preset)
        if p >= calibrationO.min_encoder and p <= calibrationO.max_encoder:
            presetsO.go_preset(outA, outB, p)
            return True
        return False
    return False

def set_preset(preset):
    presetsO.set_preset(preset)
    sLock.acquire()
    displayO.clear_frame()
    preset_list = [f"Preset {preset} set to", "",f"{str(calibrationO.real_height(motorO.counter))}"]
    displayO.show_static_frame(preset_list,len(preset_list))  
    displayO.oled.show()      
    utime.sleep(2)
    sLock.release()
                


        
# miscs

# @micropython.native    
def disable_button():
    pass

# @micropython.native  
def confirm_reset():
    sLock.acquire()
    displayO.oled.fill(0)
    displayO.show_header("F Reset",wifiO.wifi,wifiO.aps)
    displayO.show_frame()
    displayO.text_frame("All seetings and presets will be wiped, do you confirm?")
    menuO.reset_state = True
    menuO.menu_state = False
    calibrationO.system_idle = False
    sLock.release()

def confirm_reset_collision():
    sLock.acquire()
    displayO.oled.fill(0)
    displayO.show_header("C Reset",wifiO.wifi,wifiO.aps)
    displayO.show_frame()
    displayO.text_frame("Collision settings will be wiped, do you confirm?")
    menuO.collision_reset_state = True
    menuO.menu_state = False
    calibrationO.system_idle = False
    sLock.release()
    
def reset_collision():
    menuO.collision_reset_state = False
    menuO.menu_state = False
    calibrationO.system_idle = False
    calibrationO.collision_reset_state = True
    encoder_value = calibrationO.min_encoder+10
    motorO.move_motor_height("down",outA, outB, encoder_value)
    sLock.acquire()
    displayO.clear_frame()
    displayO.text_frame("Go to HIGHEST position then to LOWEST, then confirm")
    sLock.release()


        
        
        
# @micropython.native    
def factory_reset():
    sLock.acquire()
    try:
        os.remove("settings.json")
    except:
        print("File not found")
    try:
        os.remove("state.json")
    except:
        print("File not found")
    try:
        os.remove("presets.json")
    except:
        print("File not found")
    try:
        os.remove("saved_wifi.json")
    except:
        print("File not found")
    try:
        os.remove("s_v.json")
    except:
        print("File not found")
    machine.reset()
    sLock.release()


# @micropython.native
def show_presets():    
    sLock.acquire()
    menuO.presets_state = True
    menuO.menu_state = False
    calibrationO.system_idle = False
    motorO.api = False
    presets = presetsO.presets
    displayO.oled.fill(0)
    displayO.show_frame()
    if not presets:
        displayO.text_frame("There are no preset settings in place yet.")
    else:
        preset_list = ["{}: {}".format(k, calibrationO.real_height(v)) for k, v in presets.items()]
        displayO.show_static_frame(preset_list,len(preset_list))
        displayO.show_header("Presets",wifiO.wifi,wifiO.aps)
        displayO.oled.show()
    sLock.release()
    
# @micropython.native    
def show_calibration():    
    sLock.acquire()
    menuO.presets_state = True
    menuO.menu_state = False
    calibrationO.system_idle = False
    motorO.api = False
    min_max = ["Min: {}".format(calibrationO.min_real), "Max: {}".format(calibrationO.max_real)]
    displayO.oled.fill(0)
    displayO.show_frame()
    displayO.show_static_frame(min_max,len(min_max))
    displayO.show_header("Min/Max",wifiO.wifi,wifiO.aps)
    displayO.oled.show()
    sLock.release()
    
# @micropython.native
def show_ip():
#     sLock.acquire()
    menuO.presets_state = True
    menuO.wc_state = False
    menuO.wc_c_state = False
    menuO.menu_state = False
    calibrationO.system_idle = False
    motorO.api = False
    if wifiO.wlan.isconnected():
        ip = ["IP address: ",wifiO.wlan.ifconfig()[0]]
    else:
        ip = ["IP address: ","Not connected!"]
    displayO.oled.fill(0)
    displayO.show_frame()
    displayO.show_static_frame(ip,len(ip))
    displayO.show_header("IP",wifiO.wifi,wifiO.aps)
    displayO.oled.show()
#     sLock.release()
    

# @micropython.native   
def lock_unlock():
    sLock.acquire()
    menuO.presets_state = True
    menuO.menu_state = False
    calibrationO.system_idle = False
    motorO.api = False
    if not displayO.lock_state:
        displayO.lock_state = True
        lock = ["Table Locked!"]
    else:
        displayO.lock_state = False
        lock = ["Table Unlocked!"]
    displayO.oled.fill(0)
    displayO.show_frame()
    displayO.show_static_frame(lock,len(lock))
    displayO.show_header("(Un)Lock",wifiO.wifi,wifiO.aps)
    displayO.oled.show()
    sLock.release()   



def awake():
    sLock.acquire()
    global start_tm
    displayO.wake()
    start_tm = time()
    if time() - start_tm >= calibrationO.sleep_time:
        go_home()
    sLock.release()                                                                                                                                              

def stp_rem():
    buzzvibO.stop()
    sLock.acquire()
    global start_tm_rem
    displayO.stp_alarm()
    displayO.start_time = utime.ticks_ms()
    start_tm_rem = time()
    if time() - start_tm_rem >= calibrationO.reminder_time:
        go_home()
    sLock.release()
    
def handle_button(fc,args):
    awake()
    stp_rem()
    fc(*args)
    global start_tm, start_tm_rem
    start_tm = time()
    start_tm_rem = time()
    

def set_sleep_value(sleep_value):
    menuO.slp_state=False
    if sleep_value == 0 or sleep_value == 86400:
        sleep_value = sys.maxsize
    calibrationO.sleep_time = sleep_value
    sLock.acquire()
    with open("settings.json","r") as file:
        settings_json = json.loads(file.read())
        settings_json["sleep_time"] = sleep_value
    with open("settings.json","w") as file:
        file.write(json.dumps(settings_json))
    sLock.release()
    displayO.clear_frame()
    preset_list = ["Done!", "Table will sleep", f"after: {displayO.seconds_to_timestamp(sleep_value)}"]
    displayO.show_static_frame(preset_list,len(preset_list))  
    displayO.oled.show()      
    utime.sleep(2)
    displayO.oled.fill(0)
    config_menu()
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

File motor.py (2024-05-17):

"""
author: waliori
"""
import utime
import json
import uasyncio as asyncio
import uarray
import umatrix
class Motor:
    def __init__(self, pwm1, pwm2, counter,sLock,accelO,curr_sens):
        self.api = False
        self.direction = 0 # 0 for stopped, 1 for clockwise, -1 for counterclockwise
        self.pwm1 = pwm1
        self.pwm2 = pwm2
        self.counter = counter   # counter updates when encoder rotates
        self.last_counter = 0
        self.outA_last = 0 # registers the last state of outA pin / CLK pin
        self.outA_current = 0 # registers the current state of outA pin / CLK pin
        self.sLock = sLock
        self.curren_position = counter
        self.settings_valid = self.check_settings()
        self.sens_list_tresh = 9999999
        self.sens_tresh = 0
        self.block_err_cnt = 0
        self.last_pulse = 0
        self.ietrations = 0
        self.current_counter = self.counter
        self.srt = 0
        self.statesrota = 20 #encoder
        self.blocked = False
        self.slowing = False
        self.rpm = 0
        self.avg_rpm=0
        self.rpm_running_sum = 0
        self.rpm_reading_count = 0
        self.current_direction = None
        self.current_duty = 0
        self.curr_sens = curr_sens
        self.curr = 0
        self.running_sum = 0
        self.reading_count = 0
        self.avg_current = 0
        self.peak_current = 0
        self.current_threshold = 0        
        self.accelO = accelO        
        self.accel = (0,0,0)
        self.avg_xyz = (0,0,0)
        self.xyz_running_sum = (0, 0, 0)
        self.xyz_reading_count = 0
        # Initialize PCA variables
        self.min_samples = 100
        self.num_samples = 0
        self.mean = None
        self.covariance_matrix = None
        self.principal_components_up = None
        self.projected_mean_up = None
        self.principal_components_down = None
        self.projected_mean_down = None
        
    def get_calib(self):
        try:
            with open("settings.json","r") as settings:
                self.calibration_data = json.load(settings)
        except:
            self.calibration_data = {}
        print(f"{self.calibration_data}")
        
        
    def move_motor_forward(self,outA,outB,maxi):
        for duty in range(0,65025,5):
            if self.counter >= (maxi):
                self.stop_motor()
                break
            self.pwm1.duty_u16(duty)
            self.f_en(outA)
#             utime.sleep_us(1)
    
    def slow_motor_forward(self,outA,outB,maxi):
        self.slowing = True
        for duty in range(65025, 0, -5):
            if self.counter >= (maxi - 15):
                self.stop_motor()
                break
            self.pwm1.duty_u16(duty)
            self.f_en(outA)
        self.rpm = 0
        self.slowing = False
#             utime.sleep_us(1)

    def is_moving(self):
        return self.direction != 0 and self.rpm != 0
            
    def move_motor_backward(self,outA,outB,mini):
        for duty in range(0,65025,5):
            if self.counter <= (mini):
                self.stop_motor()
                break
            self.pwm2.duty_u16(duty)
            self.b_en(outA)
#             utime.sleep_us(1)
        
    def slow_motor_backward(self,outA,outB,mini):
        self.slowing = True
        for duty in range(65025, 0, -5):
            if self.counter <= (mini):
                self.stop_motor()
                break
            self.pwm2.duty_u16(duty)
            self.b_en(outA)
        self.rpm = 0
        self.slowing = False
#             utime.sleep_us(1)
        
    def stop_motor(self):
        self.pwm1.duty_u16(0)
        self.pwm2.duty_u16(0)
        self.rpm = 0
        
    def check_settings(self):
        try:
            with open("settings.json", "r") as file:
                settings = json.load(file)
            required_params = [
                "rpm_up", "reminder_time", "min_real", "current_down", "sleep_time",
                "max_real", "accel_down", "rpm_down", "min_encoder", "accel_up",
                "max_encoder", "current_up", "principal_components_up", "principal_components_down",
                "projected_mean_up", "projected_mean_down"
            ]
            return all(param in settings for param in required_params)
        except:
            return False
    
    def save_position(self):
        if self.settings_valid:
            self.sLock.acquire()
            self.curren_position = self.counter
            file=open("state.json","w")
            file.write(json.dumps({"current_encoder":self.counter}))
            file.close()
            self.sLock.release()

    def update_pca(self):
        if self.calibration_data:
            # Convert averaged sensor data to a list
            sensor_data = [self.avg_xyz[0], self.avg_xyz[1], self.avg_xyz[2], self.avg_rpm, self.avg_current]
            # Normalize the sensor data
            normalized_data = self.normalize_data(sensor_data)
            # Update mean
            if self.num_samples == 0:
                self.mean = normalized_data.copy()
            else:
                for i in range(len(self.mean)):
                    self.mean[i] = (self.num_samples * self.mean[i] + normalized_data[i]) / (self.num_samples + 1)

            # Update covariance matrix
            if self.num_samples == 0:
                self.covariance_matrix = [[0] * 5 for _ in range(5)]
            else:
                centered_data = [normalized_data[i] - self.mean[i] for i in range(len(normalized_data))]
                for i in range(5):
                    for j in range(i, 5):
                        self.covariance_matrix[i][j] += centered_data[i] * centered_data[j]
                        self.covariance_matrix[j][i] = self.covariance_matrix[i][j]

            self.num_samples += 1
            if self.num_samples <= self.min_samples:
                # Compute eigenvalues and eigenvectors
                eigenvalues, eigenvectors = self.compute_eigen(self.covariance_matrix)

                # Sort eigenvectors by decreasing eigenvalues
                sorted_indices = sorted(range(len(eigenvalues)), key=lambda i: eigenvalues[i], reverse=True)
                sorted_eigenvalues = [eigenvalues[i] for i in sorted_indices]
                sorted_eigenvectors = [[eigenvectors[j][i] for j in range(5)] for i in sorted_indices]

                # Select principal components
                num_components = 2  # Number of principal components to retain
                principal_components = [sorted_eigenvectors[i] for i in range(num_components)]
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

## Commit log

2023-06-06 Fix: #11, decuple display from wifi and add connecting... message
    [calibration.py, display.py, menu.py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]
2023-06-06 Fix: #14, handle go back menu
    [wifi.py]
2023-06-08 Fix: #8, add screen dim for main screen after 'time'
    [display.py, menu.py, wifi.py]
2023-06-12 Fix #20 - Add a new menu item to set sleep time
    [calibration.py, display.py, menu.py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]
2023-06-12 fix #20 minor fix
    [calibration.py, wifi.py]
2023-06-12 fix #20 minor fix 2
    [calibration.py]
2023-06-25 Fix #21 #22 added start or stop AP
    [calibration.py, display.py, menu.py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]
2023-06-29 Fix #12, fix #27, + some minor changes
    [menu.py, wifi.py]
2023-06-29 Fix #6 + some error handeling
    [menu.py, wifi.py]
2023-06-29 Fix #7 + measure unit agnostic
    [calibration.py, display.py, wifi.py]
2023-06-29 fix calibration reset
2023-06-30 Fix #5 added reminder to stand
    [calibration.py, display.py, menu.py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]
2023-07-07 Fix #37 fix #34 fix #41 fix #43
    [calibration.py, motor.py]
2023-07-13 Fix #44, Fix #47
    [display.py, motor.py]
2023-10-19 first addition of sound/vibration module WIP
    [buzz_vib.py, display.py, motor.py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]
2023-10-21 Fix #48, Fix #51, Fix #58
    [buzz_vib.py, display.py]
2024-01-06 Fix #73 - screen rotation and knob menu direction
    [display.py, main.py, menu.py]
2024-01-18 Fix #73 #74 #77 #79 #80
    [main.py, menu.py, motor.py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]
2024-04-06 simplification of accelerometer
2024-04-06 handle memory allocation issues using the html long string
    [wifi.py]
2024-04-06 initial dev collision - add accel,curr,rpm tresh in settings.json
    [calibration.py, main.py, motor.py]
2024-04-06 maybe fix alarm go on after 24 even if its set to "never"
    [main.py]
2024-04-10 update collision reset mechanism
    [calibration.py, collision.py, main.py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]
2025-08-05 docs: Complete documentation overhaul based on real wiring schema
    Major Updates:
    - ✅ Fixed dual encoder system documentation (left: position, right: UI)
    - ✅ Corrected all GPIO pin assignments to match actual code implementation
    - ✅ Updated data flow architecture to reflect real system design
    - ✅ Added comprehensive hardware documentation with accurate BOM
    - ✅ Enhanced troubleshooting with dual encoder diagnostic procedures
    - ✅ Updated setup guides with correct wiring information
    - ✅ Improved software architecture docs with actual GPIO mappings
    Technical Changes:
    - Verified all pin assignments against setup.py (authoritative source)
    - Analyzed wiring_video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
2025-08-09 add fritzing diagram
    [wiring-diagram.fzz]

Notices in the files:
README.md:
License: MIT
